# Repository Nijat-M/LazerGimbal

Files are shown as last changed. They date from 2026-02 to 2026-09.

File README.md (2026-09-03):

# 🎯 SADIR 1798-K

<div align="center">

### Autonomous Air Defense & Precision Optical Laser Tracking System
**2-Axis High-Speed Closed-Loop Gimbal with Real-Time Computer Vision, IFF Defense & STM32 Firmware**







<p align="center">
  
  
  
  
  
  
</p>

[🇬🇧 English](README.md) • [🇹🇷 Türkçe](README_TR.md)

</div>

---

<div align="center">

### 📋 TEKNOFEST 2026 Yarışma / Başvuru Bilgileri

| Başvuru Yaptığı Takım Adı | Takım ID | Başvuru ID |
| :---: | :---: | :---: |
| **Sadir Pehlivan** | **#990060** | **#5208679** |

</div>

---

## 📸 System Hardware & Field Deployment

<div align="center">
  <table>
    <tr>
      <td width="58%" align="center" valign="middle">
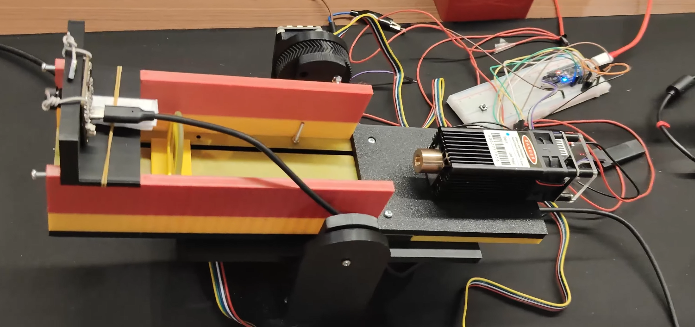
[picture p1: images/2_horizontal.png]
Laser Gimbal Hardware Rig (Close-up)
        
        <p><b>🔬 Hardware Prototype (Close-up)</b><br>
        <i>2-Axis Custom Gimbal, Optical Rail, High-Power Laser Module, Arducam Global Shutter & STM32 Controller</i></p>
      </td>
      <td width="42%" align="center" valign="middle">
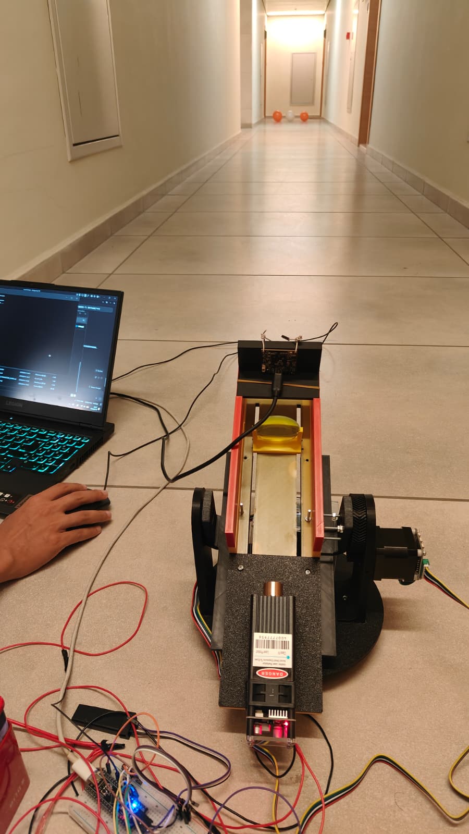
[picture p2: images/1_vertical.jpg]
15m Hallway Target Engagement Field Test
        
        <p><b>🎯 15m Long-Range Field Test</b><br>
        <i>Live Corridor Target Acquisition, Autonomous Lock-On & Real-Time PC Telemetry</i></p>
      </td>
    </tr>
  </table>
</div>

---

## 📺 Demonstration Video

<div align="center">

### 🏆 [2026 Çelikkubbe Hava Savunma Sistemleri Yarışması | Başvuru ID: 5208679](https://www.youtube.com/watch?v=ou6Uf3Ik7QI)

2026 Çelikkubbe Hava Savunma Sistemleri Yarışması | Başvuru ID: 5208679 (https://www.youtube.com/watch?v=ou6Uf3Ik7QI)

*Click the thumbnail above to watch the official competition video featuring Stage 3 autonomous engagement, live IFF friendly-protection, and precision laser tracking.*

</div>

---

## 📌 Executive Summary

**LazerGimbal SADIR 1798-K** is an industrial-grade, 2-axis closed-loop optical laser tracking and air defense gimbal platform engineered for precision target acquisition, identification, and neutralisation. Built for **TEKNOFEST 2026 Çelikkubbe Air Defense Systems Competition**, the system tightly integrates high-speed computer vision with real-time embedded hardware control.

The system is architected across three core pillars:
1. **Host AI & Vision Engine (PC / PyQt6 / Python)**: Processes live camera streams at 60 FPS (using global shutter sensors), runs multi-space IFF (Identification Friend or Foe) chromatic algorithms, and executes Ultralytics YOLO26 deep-learning target classification with zero NMS latency.
2. **Real-Time Embedded Controller (STM32F401 / C HAL)**: Executes a continuous 10kHz hardware DDA (Digital Differential Analyzer) microstep pulse engine and a 50Hz Incremental PID loop driving **Makerbase MKS SERVO42C closed-loop vector stepper motors (`CR_vFOC`)** with absolute zero step loss and high holding torque.
3. **Yetenek 6 Zero-Annotation Synthetic Pipeline**: A synthetic dataset generator that automatically renders 3MF CAD meshes into multi-angle photorealistic targets, generating labeled YOLO26 training datasets without manual bounding box annotation.

---

## 🚀 Key Innovations & Features

### 🛡️ Stage 3 Autonomous Air Defense & IFF Engine
- **Autonomous Mission Director**: A 6-state competition state machine handling target acquisition, hostile engagement, post-fire evaluation (10s), automated emergency stop (ESTOP), stabilization delay (10s), and safe shutdown.
- **Robust Multi-Space IFF (Friend or Foe)**: Combines HSV, normalized BGR differential, and CIELAB chroma spaces to reliably classify Red Hostile vs. Blue Friendly targets while eliminating ambient background false-positives (yellow walls, wood frames).
- **100% Friendly Fire Prevention**: Real-time safety interlock strictly suppresses laser firing whenever a friendly blue asset enters the reticle zone.
- **Orange Balloon Hunt Mode**: Auto-locks and engages orange balloon targets continuously until physical balloon destruction is optically verified.

### 👁️ Computer Vision & Tactical HUD (PyQt6 / Python)

<div align="center">
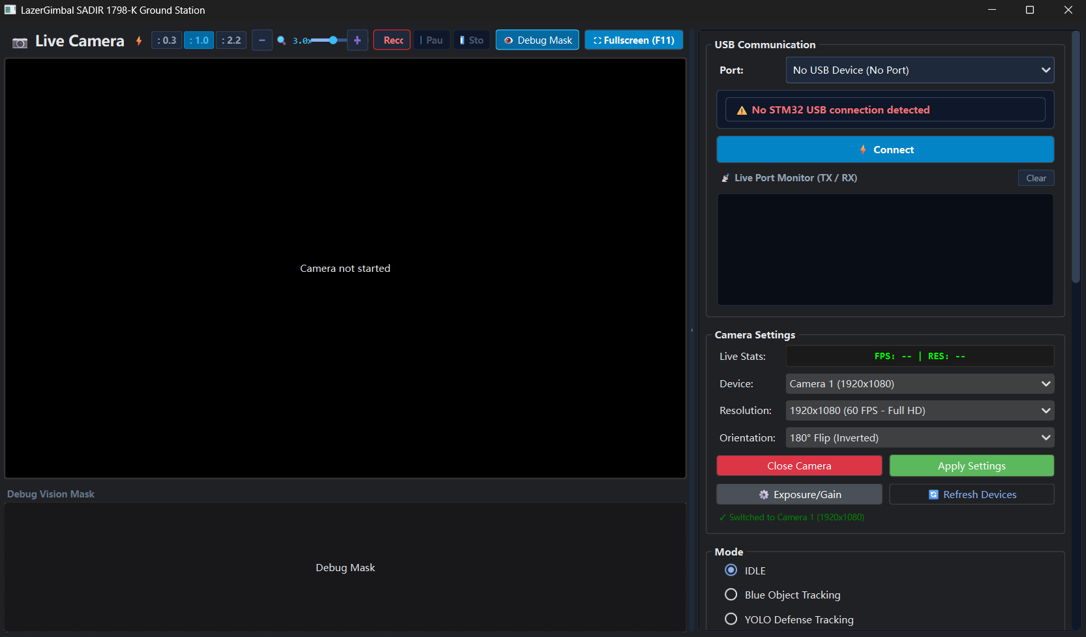
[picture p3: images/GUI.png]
Tactical GUI Dashboard
  
  <p><i>Modern Cyber-Dark PyQt6 Tactical Interface — Live Camera Feed, Dual Target Lock-On, Debug Vision Mask & Device Control</i></p>
</div>

- **Arducam AR0234 Global Shutter Camera Support**: Fully adapted for high-speed industrial global shutter sensors (1080p @ 60 FPS), eliminating rolling-shutter jello distortion under aggressive gimbal slewing.
- **Tactical PiP Zoom Reticle**: Picture-in-Picture digital magnification scope synchronized in real time with the calibrated aim crosshair.
- **Constant Frame Rate (CFR 30fps) Video Recording**: Audio-video synced `.mp4` hardware container recording with microphone ambient audio mix and full telemetry HUD OSD overlay.
- **Zero-Flicker Spatial Multi-Target Tracker**: Multi-object Euclidean association and Kalman smoothing to eliminate bounding box flickering and ID swaps.
- **Dynamic Orientation Hot-Switching**: Instant 0° / 180° inverted ceiling mount and horizontal mirror modes without software restarts.

### ⚡ Embedded Motion Control (STM32F401 / C HAL)
- **10kHz Continuous-Phase DDA Pulse Engine**: Microstep generator preserving fractional step accumulators across control cycles for ultra-smooth low-speed tracking.
- **50Hz Incremental Closed-Loop PID**: Fine-tuned closed-loop tracking with dynamic deadband compensation and friction anti-stall minimum torque feed.
- **3-Speed Motor Gearbox**: Fast toggle (Keys `1`, `2`, `3`) for Recon, Cruise, and Sprint manual motor slewing speeds.
- **5-Layer Safety Protection**:
  1. **Surge Auto-Healing Reset**: Exception handlers instantly clamp motor pins to 0V and trigger a 1ms auto-reboot (`NVIC_SystemReset()`).
  2. **Dual Watchdog Timers**: 500ms hardware telemetry timeout halts STEP pulses if communication drops; PC watchdog stops stale commands after 250ms.
  3. **Velocity & Acceleration Limiting**: Bounded motor dynamics preventing step slippage.
  4. **Coordinate Boundary Clamping**: Filters UART transmission noise.
  5. **Non-Blocking Heartbeat Indicator (`PC13`)**: Visual hardware health feedback.

### 🧠 Yetenek 6 — 3MF Synthetic Training & Classification
- **Zero-Manual-Annotation Pipeline**: Converts official competition 3MF multi-body files (`Modeller.3mf`) to STL meshes and renders realistic multi-angle targets onto real ambient backgrounds.
- **Multi-Class Air Defense Detection**: Classifies `F16` fighter jets, `HELIKOPTER` attack helicopters, `BALISTIK_FUZE` ballistic missiles, and `MINI_IHA` mini-drones across 5m, 10m, and 15m test ranges.

---

## 🛠️ Hardware Bill of Materials (BOM)

| Component | Model / Specification | Purpose |
| :--- | :--- | :--- |
| **Microcontroller** | STM32F401CCU6 (Blackpill / ARM Cortex-M4 @ 84MHz) | Real-time motion control & DDA pulse engine |
| **Motors & Drivers** | 2x NEMA 17 Stepper Motors + MKS SERVO42C Closed-Loop FOC | 2-axis Pan/Tilt drive with magnetic encoder feedback |
| **Camera Sensor** | Arducam AR0234CS Global Shutter USB Camera (1080p @ 60fps) | High-speed, distortion-free optical acquisition |
| **Laser Emitter** | 450nm High-Power Blue Laser Diode & Optics Rail | Precision target illumination & simulated engagement |
| **Power Supply** | 20V DC 2A+ Regulated Switching Power Supply | Motor power rail (`V+` / `GND`) |
| **Pan-Tilt Frame** | Custom reinforced 3D printed mechanical assembly | 2-axis rigid optical gimbal platform |

### 🔌 Hardware Pinout & Electrical Interface

| Subsystem | Signal Name | STM32F401 Pin | Connected Peripheral / Pin | Logic / Note |
| :--- | :--- | :--- | :--- | :--- |
| **Pan Axis (X)** | `X_STEP` | `PA0` (TIM2_CH1) | MKS SERVO42C `STP` Pulse | 3.3V Logic (Active High) |
| **Pan Axis (X)** | `X_DIR` | `PA4` (GPIO) | MKS SERVO42C `DIR` Direction | CW / CCW Polarity |
| **Tilt Axis (Y)** | `Y_STEP` | `PA1` (TIM2_CH2) | MKS SERVO42C `STP` Pulse | 3.3V Logic (Active High) |
| **Tilt Axis (Y)** | `Y_DIR` | `PA5` (GPIO) | MKS SERVO42C `DIR` Direction | CW / CCW Polarity |
| **Laser Emitter** | `LASER_PWM` | `PB0` (TIM3_CH3) | Laser Driver Optocoupler / TTL | 1kHz PWM Power / Gate Trigger |
| **Status Telemetry**| `HEARTBEAT` | `PC13` (GPIO) | On-board Blue LED | 500ms Non-blocking Pulse |
| **Host Link** | `USB_CDC` | `PA11` (DM) / `PA12` (DP) | PC USB 3.0 / USB-C Port | Native 12 Mbps Full-Speed CDC |
| **Motor Power** | `20V_RAIL` | External PSU | MKS Driver `V+` / `GND` | Common Ground (`COM` to STM32 GND) |

> [!NOTE]
> **Hardware Roadmap**: Breadboard wiring is utilized for rapid prototyping during preliminary trials. A custom integrated surface-mount PCB carrier board is currently in development for the final competition stage.

---

## 📂 Project Structure

```text
LazerGimbal/
├── main.py                     # Main application entry point (PyQt6 + PyTorch DLL guard)
├── run_app.bat                 # One-click Windows launch script
├── requirements.txt            # Python dependencies
├── Modeller.3mf                # Official 3MF 3D target models
├── CHANGELOG.md                # Detailed release notes & commit history
│
├── core/                       # Control & State Machine Layer
│   ├── gimbal_controller.py    # 40Hz visual tracking controller with PID & safety watchdog
│   ├── serial_thread.py        # Asynchronous high-speed serial UART communication
│   ├── stage3_mission_director.py # Stage 3 autonomous air defense state machine
│   └── control/                # Error calculation & manual mouse aim controllers
│
├── vision/                     # Computer Vision & Deep Learning Layer
│   ├── vision_worker.py        # Video capture, detection dispatcher, PiP scope & video recorder
│   ├── iff.py                  # Identification Friend or Foe (HSV + BGR + CIELAB)
│   ├── yolo_detector.py        # Ultralytics YOLO26 inference pipeline & defense model adapter
│   ├── yetenek6_detector.py    # Yetenek 6 target detection adapter
│   └── yetenek6_stabilizer.py  # Spatial-temporal anti-jitter stabilizer
│
├── gui/                        # User Interface Layer (PyQt6)
│   ├── main_window.py          # Main dashboard window & docking layout
│   └── widgets/                # Modular UI widgets (Camera, Control, Mode, IFF, Calibration, PID)
│
├── config/                     # Configuration & Calibration Storage
│   ├── vision_config.py        # Camera FOV, resolution, color profiles, aim offset
│   ├── control_config.py       # PID parameters, speed gears, motion limits
│   ├── hardware_config.py      # Serial port baud rate & step pulse definitions
│   ├── device_config.py        # Persistent hardware & camera settings
│   ├── tracking_parameters.py  # Runtime tracking & Kalman filter dynamics
│   └── yetenek6_config.py      # Yetenek 6 distance & target metrics
│
├── STM32F401/                  # Embedded MCU Firmware (C / STM32CubeIDE)
│   ├── Core/Src/main.c         # DDA pulse engine, incremental PID & safety handlers
│   └── Lazer_F401.ioc          # STM32CubeMX hardware pinout configuration
│
├── yetenek6/                   # Synthetic Dataset & YOLO26 Training Pipeline
│   ├── README_ZH.md            # Detailed pipeline guide (Chinese)
│   ├── HIZLI_BASLANGIC_TR.md   # Quick start guide (Turkish)
│   ├── models_3mf/             # Extracted STL model assets (F16, Helicopter, Missile, Drone)
│   ├── backgrounds/            # Real background environments for synthetic overlay
│   └── scripts/                # S0 Camera test -> S1 Render -> S2 Dataset -> S3 Train -> S4 Detect
├── docs/                       # Technical Research, Parameter Tuning & Roadmaps
│   ├── Phase3_Kalman_Tracking_Plan.md # Kinematic state estimation & EKF plan
│   ├── Phase4_Future_Industrial_Upgrades.md # IMU cascade, ADRC & PnP fire control plan
│   └── TRACKING_PARAMETERS_GUIDE.md # Parameter tuning baselines & physical formulas
│
└── tests/                      # Automated Unit & Integration Tests
    ├── test_stage3_balloon.py  # Stage 3 balloon defense & mission state machine test
    ├── test_balloon_hunt.py    # Orange balloon segmentation & shape validation
    ├── test_iff_color.py       # IFF chromatic discrimination test
    └── test_manual_mouse_control.py # Gimbal motion & serial command verification
```

---

## ⚡ Quick Start

### 1. Prerequisites
- **Operating System**: Windows 10 / 11 (64-bit)
- **Python**: 3.10 or higher
- **NVIDIA GPU** (Optional for CUDA-accelerated YOLO26 inference)

### 2. Installation
```bash
# Clone repository
git clone https://github.com/Nijat-M/LazerGimbal.git
cd LazerGimbal

# Create virtual environment
python -m venv .venv
.venv\Scripts\activate

# Install dependencies
pip install -r requirements.txt
```

### 3. Launch Application
```bash
python main.py
# Or run with the bundled batch file:
run_app.bat
```

---

## 📜 License & Acknowledgments

This project is licensed under the **[MIT License](LICENSE)**.

Developed for **TEKNOFEST 2026 Çelikkubbe Air Defense Systems Competition** (Takım: **Sadir Pehlivan**, Takım ID: **#990060**, Başvuru ID: **#5208679**). Special thanks to the open-source robotics and computer vision communities.

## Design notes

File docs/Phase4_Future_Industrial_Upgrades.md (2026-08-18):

# 阶段四：未来工业级控制架构升级计划 (Phase 4: Future Industrial Upgrades)

> **基准平台**：MKS SERVO42C 闭环步进系统 + STM32F401 (10kHz TIM2 DDA 步进脉冲) + 原生 USB CDC (12 Mbps) + Arducam AR0234 全局快门相机 (60 FPS) + YOLO26 目标检测  
> **目标**：对标 RoboMaster 竞赛步兵/哨兵云台及工业级光电吊舱，探索更高精度的控制算法与火控解算体系。

---

## 方案一：IMU 异构高频融合串级控制与 ADRC（自抗扰控制）

当前系统已具备下位机 10kHz DDA 步进脉冲生成与上位机 60Hz 动态超前预测。为了进一步抑制物理机械扰动（如线材拉扯阻力、减速机回差、安装基座振动），可引入多传感器融合与现代抗扰控制。

### 1. 异构双闭环串级控制 (Cascade Control)
- **核心架构**：
  - **外环（位置/角度环，60Hz）**：由上位机 60 FPS 视觉目标检测提供目标在视野中的角度偏差。
  - **内环（角速度环，1000Hz）**：在云台载荷端加装 6 轴 IMU（如 MPU6050 或工业级 ICM-42688-P），STM32 通过 I2C/SPI 以 1kHz 频率采集陀螺仪角速度 ($\omega_{\text{yaw}}, \omega_{\text{pitch}}$)。
- **技术优势**：
  - 上位机只需下发目标角速度或相对位姿，STM32 内部以 1000Hz 极高刷新率稳定角速度内环。
  - 彻底隔离外部基座晃动对视轴的干扰，实现类似微单稳定器 / 军用吊舱的独立增稳。

### 2. ADRC 自抗扰控制 (Active Disturbance Rejection Control)
- **核心思想**：利用**扩张状态观测器 (ESO)**，把系统中所有未知的外部干扰（风阻、线束弹性阻力、非线性摩擦力）以及系统内部的模型失配统一视为“总扰动”进行实时估算，并在控制输出时施加前馈反向抵消。
- **技术优势**：
  - 相比传统 PID，ADRC 无需针对不同载荷重量或摩擦力繁琐重新整定参数，自适应鲁棒性极高。

---

## 方案二：针孔相机内参标定 (Pinhole & PnP) 与火控提前量解算 (Kinematic Lead Computing)

### 1. 相机内参标定与 3D 物理射线映射
- **当前现状**：控制输入基于图像像素误差（pixel error），存在非线性光学畸变与视场角几何非线性。
- **升级目标**：
  - 使用棋盘格标定板与 OpenCV `cv2.calibrateCamera` 标定出相机的内参矩阵 $K$ 与畸变系数 $D$。
  - 将二维像素坐标 $(u, v)$ 通过逆投影矩阵还原为物理空间相机坐标系下的 3D 视线向量 $(\vec{X}, \vec{Y}, \vec{Z})$，直接解算出目标的绝对偏航角 (Yaw) 与俯仰角 (Pitch)。

### 2. 高机动目标火控提前量解算 (Ballistic Lead Computing)
- **核心逻辑**：
  - 系统从“光子撞击 CMOS 曝光” -> “USB 帧传输” -> “GPU YOLO 推理” -> “USB CDC 下发” -> “步进电机物理转动加速” 存在固定的全链路时间延迟 $t_{\text{delay}}$。
  - 测量并校准端到端延迟队列时间戳（约 $50 \sim 70\text{ms}$）。
  - 结合目标当前速度与加速度向量，求解超前预判击中点：
    $$ P_{\text{aim}} = P_{\text{current}} + \vec{V} \cdot t_{\text{delay}} + \frac{1}{2} \vec{A} \cdot t_{\text{delay}}^2 $$
  - 云台视轴直接指向目标在 $t_{\text{delay}}$ 后的预期落点，实现真正的“指哪打哪、极速封锁”。

---

## 3. 进阶路线图 (Milestones)

| 阶段 | 课题名称 | 关键技术点 | 难度 |
| :--- | :--- | :--- | :---: |
| **Phase 4.1** | 相机内参标定与角度几何解算 | `cv2.calibrateCamera`、去畸变、像素到物理弧度映射 | ★★☆☆☆ |
| **Phase 4.2** | 全链路延时测定与提前量解算 | 端到端时间戳对齐、火控预测落点计算 | ★★★☆☆ |
| **Phase 4.3** | 硬件 IMU 陀螺仪接入与 1kHz 速度内环 | STM32 SPI/I2C 驱动 ICM-42688-P，角速度反馈内环 | ★★★★☆ |
| **Phase 4.4** | 扩张状态观测器 (ESO) 与 ADRC 控制律 | 离散 ADRC 算法在 STM32 裸机上的高频部署与抗扰验证 | ★★★★★ |

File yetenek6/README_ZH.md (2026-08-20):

# Yetenek 6 — 目标探测与分类：分步实施指南

> **要求原文**：5 m、10 m、15 m 三个距离上完成不同目标类型的探测与分类，并**在用户界面上展示**能分类为 **F16 / Mini-Micro İHA / Füze / Helikopter**。
>
> **前提**：你们相机 + UI 已跑通，PC 带独显，只有 3MF 文件，目标是**先过视频这关**。
>
> **总工时**：约 17–28 小时。两人并行 1.5–2 天。

---

## 核心思路：为什么不用人工标注

你们有 3MF（三维网格文件）。用它可以**同时**做两件事：

1. **渲染出多视角贴图素材** → 合成训练图像，**边界框由程序自动算出**，人工标注量 = 0
2. **渲染出高分辨率正视图** → 送打印店做实体靶标

因为视频里的靶标是**平面打印件**，而合成数据本质上就是"把平面素材贴到背景上"——**仿真和现实高度一致**，这是这套方案精度能上来的根本原因。

**不要为了视频去 3D 打印靶标。** 一个 60 cm 的模型拆件打印要 20–40 小时，四类目标一周起步，来不及。规范能力 6 的原文分类对象就是「görseller（图像）」，打印平面靶标完全合规。

---

## 环境准备

```bash
pip install trimesh lxml networkx pillow numpy opencv-python
pip install ultralytics          # 训练与推理
pip install PyQt5                # 若 UI 用 PyQt
```

把 3MF 文件按**类别名**命名放进 `models_3mf/`：

```
models_3mf/
├── F16.3mf
├── HELIKOPTER.3mf
├── BALISTIK_FUZE.3mf
└── MINI_IHA.3mf
```

> 文件名 = 类别名，后面全流程自动沿用，UI 上会显示成 `F16 / Helikopter / Balistik Füze / Mini/Micro İHA`。

---

## 步骤 0 — 20 分钟的可行性体检（**千万别跳过**）

整个方案成败取决于一个数字：**15 m 处目标有多少像素**。先量出来。

**A. 测相机水平视场角（HFOV）**

1. 拿一个已知宽度的物体（比如 1.00 m 的纸板），放在**正好 5.00 m** 处
2. 用你们的相机拍一帧，在看图软件里量出它的**像素宽度**
3. 运行：

```bash
cd scripts
python s0_kamera.py --img_w 1920 --ref_m 1.0 --ref_d 5.0 --ref_px 640 --target_m 0.6
```

**B. 看输出的判断**

| 15 m 处像素宽 | 结论 |
|---|---|
| ≥ 80 px | 很好，直接往下走 |
| 45–80 px | 可以，训练/推理必须用 `imgsz 960` |
| 28–45 px | 临界，用 `imgsz 1280` **并且加大靶标** |
| < 28 px | **不行**，必须加大靶标或换窄视场（长焦）镜头 |

脚本最后会直接告诉你：**要在 15 m 达到 60 px，靶标需要多宽**。按这个数字去定打印尺寸。

> 规范对靶标/图像的尺寸**没有任何限制**，所以最省事的解法就是把靶标做大。60–80 cm 是个安全区间。

---

## 步骤 1 — 从 3MF 生成素材和打印图（约 30 分钟）

```bash
cd scripts
python s1_render.py --models_dir ../models_3mf --out ../out \
    --views 200 --size 512 --poster_cm 60 --poster_dpi 150
```

输出两样东西：

| 目录 | 内容 | 用途 |
|---|---|---|
| `out/sprites/<类别>/` | 每类 200 张多视角透明 PNG | 步骤 3 合成训练数据 |
| `out/posters/` | 每类 3 个颜色（红/蓝/灰）的 60 cm @150dpi 大图 | 步骤 2 送打印 |

**关键参数说明**

- `--az_range -38 38`：水平视角范围。**因为最终拍的是平面靶标，这里要收窄**（默认已收窄）。如果你们决赛要拍 3D 实体，再放宽到 `-180 180`
- `--colors kirmizi,mavi,gri`：红=敌、蓝=友、灰=中性。红蓝两色**顺便把能力 7 的素材也做出来了**，不用重复工作
- 不需要 Blender，纯 numpy + Pillow，Windows 上直接能跑

只要打印图不要训练素材时加 `--poster_only`（几秒钟出结果）。

---

## 步骤 2 — 今天就把靶标送去打印（**这是唯一的外部依赖，最容易卡住**）

拿 `out/posters/*.png` 去打印店：

- **规格**：60 cm 宽（或步骤 0 算出来的尺寸）、哑光相纸或 PP 背胶
- **裱板**：KT 板 / 泡沫板，**沿飞机轮廓裁形**（不要裁成方块——方块会让模型学到"矩形=目标"这种错误特征）
- **数量**：四类各 1 张灰色/红色版即可满足能力 6；能力 7 另需 1 红 2 蓝
- **支架**：每张背后粘一根细木条 + 简易三脚支撑，能立在地上

> 打印店当天到隔天出货。**今天下单**，别等到模型训完才想起来。成本几十里拉。

---

## 步骤 3 — 拍 30–40 张场地背景照（30 分钟，**决定精度上限**）

去你们**实际要拍视频的场地**，用**同一台相机、同样的架设高度**，拍 30–40 张空场景照片（不放靶标），涵盖：

- 不同朝向、不同时间段的光照
- 有人走动、有杂物的画面
- 阴天/晴天各来一些

放进 `backgrounds/` 目录。

> **这一步是整套方案里性价比最高的 30 分钟。** 用真实场地背景合成的数据，比用程序生成的假背景，实测精度差距非常大——因为模型不会再把背景里的杂物误判成目标。跳过这步，脚本会自动用合成背景，但误检率会明显上升。

---

## 步骤 4 — 合成训练数据集（15–25 分钟机器时间）

```bash
python s2_dataset.py --sprites ../out/sprites --bg ../backgrounds \
    --out ../dataset --n_train 5000 --n_val 500 \
    --img_w 1920 --img_h 1080 --hfov 60 --target_m 0.6
```

> `--img_w/--img_h` 填**你们相机的真实分辨率**，`--hfov` 填步骤 0 量出来的值，`--target_m` 填靶标实际宽度。

脚本干了什么：

- 目标在画面中的像素尺寸由**真实光学公式**推算：`px = img_w × 靶标宽 / (2 × 距离 × tan(HFOV/2))`
- **55% 的样本集中在 5/10/15 m 附近**（±15% 抖动），其余在 3.5–18 m 均匀分布 —— 精准对齐规范要求的三个距离
- 随距离增加模糊、亮度/对比度抖动、噪声、JPEG 压缩、旋转
- **边界框从 alpha 通道自动精确算出**，写成 YOLO 格式
- 自动生成 `data.yaml`

运行完会打印一张**像素尺寸参考表**，再确认一次 15 m 的数值合理。

---

## 步骤 5 — 训练（1–2 小时，挂机）

```bash
python s3_train.py --data ../dataset/data.yaml --model yolov8s.pt \
    --imgsz 960 --epochs 80 --batch 8 --device 0
```

**⚠️ 最容易犯的错：用默认 `imgsz 640`。**
15 m 处目标只有 40–60 px，640 输入下会被压到 15–20 px，小目标召回会断崖式下跌。**必须用 960，紧张的话用 1280。**

其他建议：

- 显存不够就调 `--batch 4`，或换 `yolov8n.pt`（更快、精度略低，对四类靶标够用）
- 训完看 `runs/detect/yetenek6/`：**mAP50 ≥ 0.85** 就可以进入下一步
- 权重在 `runs/detect/yetenek6/weights/best.pt`

---

## 步骤 6 — 真实数据微调（**强烈建议，2 小时，效果最明显**）

靶标打印回来后，在场地上按 5/10/15 m 摆好，**每类录 30 秒视频**，抽帧得到 150–300 张真实图。

- 用 [Roboflow](https://roboflow.com) 或 `labelImg` 标注 —— 只有 200 来张，**一个人 1 小时能标完**
- 混进 `dataset/images/train`，用合成模型做起点再训 20–30 epoch：

```bash
python s3_train.py --data ../dataset/data.yaml \
    --model runs/detect/yetenek6/weights/best.pt \
    --imgsz 960 --epochs 30 --name yetenek6_ft
```

这一步通常能把真实场景的 mAP 再拉高 10–20 个点，是**合成数据方案的标准收尾**。

---

## 步骤 7 — 接进你们现有的 UI（3–5 小时）

因为相机→界面链路已经通了，改动量很小：

```python
from s4_detector import HedefDedektoru

# 初始化一次
self.det = HedefDedektoru("best.pt", conf=0.35, imgsz=960,
                          hfov_deg=60, hedef_genislik_m=0.6)   # 后两个参数可选

# 原来的每帧循环里：
#   self.label.setPixmap(self.mat2pix(frame))
# 改成：
dets = self.det.tespit(frame)
self.label.setPixmap(self.mat2pix(self.det.ciz(frame, dets)))
self.tablo_guncelle(dets)      # 右侧分类列表
```

`dets` 是标准结构，方便你们接自己的逻辑：

```python
[{'sinif': 'F16', 'gorunen': 'F16', 'guven': 0.94,
  'box': (x1,y1,x2,y2), 'mesafe_m': 5.1}, ...]
```

`s5_ui_pyqt.py` 是一个可直接运行的完整 PyQt 面板（左边视频 + 右边分类表格），可以整段抄，也可以直接拿来当演示界面：

```bash
python s5_ui_pyqt.py --weights best.pt --source 0 --hfov 60 --target_m 0.6
```

**界面细节（裁判会看这些）**

- 标签用 PIL 绘制，正确显示土耳其字符 `Füze`、`İHA`（`cv2.putText` 显示不出来，这是个常见坑）
- 每类一个固定颜色，右侧表格实时列出 **HEDEF TİPİ / GÜVEN / MESAFE**
- 顶部信息条显示当前检测数量

> **距离显示是加分项，不是必需项。** 规范原文只要求「在这三个距离上完成探测和分类，并通过用户界面展示」——距离是**布置条件**，不是界面必须输出的数值。给 `hfov_deg` 和 `hedef_genislik_m` 就能顺带估出距离，不给就显示 `-`，**不要为此单独做测距模块**。

---

## 步骤 8 — 拍摄能力 6 的镜头（1 小时）

拍摄清单，逐条对照：

- [ ] 地面用**卷尺量出并贴标记** 5 m / 10 m / 15 m，让标记在画面里可见
- [ ] 每个距离**依次放上四类靶标**，镜头**同时拍到实景 + UI 屏幕**
  - 最佳做法：**屏幕录制 UI** + **手机拍现场**，后期做画中画
- [ ] UI 上必须能清楚看到**框 + 类别名 + 置信度**
- [ ] 开头打字幕卡：`Yetenek 6 — Hedef Tespit ve Sınıflandırma`
- [ ] 画面里用字幕或纸牌标出当前距离：`5 m` / `10 m` / `15 m`
- [ ] 建议 40–60 秒拍完（总时长只有 2–5 分钟，7 项能力要挤进去）

---

## 排期建议（今天 8/16 → 截止 8/20 17:00）

| 日期 | 任务 |
|---|---|
| **8/16 今天** | 步骤 0 视场角实测 → 定靶标尺寸 → **步骤 1 生成打印图 → 送打印店** → 步骤 3 拍背景照 → 步骤 4 合成数据集（跑通宵） |
| **8/17** | A：步骤 5 训练；B：步骤 7 UI 集成（**并行**） |
| **8/18** | 靶标到货 → 步骤 6 真实数据微调 → 三距离实测调参 |
| **8/19** | **拍摄全部 7 项能力 + 剪辑**（留一整天） |
| **8/20 上午** | 上传 YouTube（设「Liste dışı」）→ 描述里写时间戳 → 填 KYS 表单 → **验证链接能打开** |

> 链接打不开会**直接淘汰**，务必用无痕窗口验证一遍。

---

## 排障速查

| 现象 | 原因 / 解法 |
|---|---|
| 15 m 完全检不到 | `imgsz` 太小 → 上 1280；或靶标太小 → 重回步骤 0 重算尺寸 |
| 背景杂物被误检 | 没用真实场地背景 → 补做步骤 3，或降低 `--conf` 阈值反向验证 |
| 类别互相混淆 | 素材视角范围太宽 → 收窄 `--az_range`；或补真实数据微调（步骤 6） |
| 帧率太低卡顿 | 换 `yolov8n`；或推理降到 `imgsz 640` 但只对画面中心 ROI 裁剪后送入 |
| UI 上土耳其字符是方块 | 用 `s4_detector.ciz()`（PIL 绘制），别用 `cv2.putText` |
| 3MF 加载报错 | 用 PrusaSlicer / Bambu Studio 打开后导出 STL，把 `s1_render.py` 里的 `*.3mf` 改成 `*.stl` |
| 训练 loss 不降 | 检查 `data.yaml` 的 `names` 顺序和 `sprites/` 子目录名是否一致（脚本按字母序编号） |

---

## 文件清单

```
scripts/
├── s0_kamera.py      # 视场角测量 + 靶标尺寸规划（先跑这个）
├── s1_render.py      # 3MF → 多视角素材 + 打印海报
├── s2_dataset.py     # 素材 → YOLO 数据集（自动标注）
├── s3_train.py       # YOLOv8 训练
├── s4_detector.py    # 推理模块（接进你们 UI）
└── s5_ui_pyqt.py     # 完整 PyQt 演示面板
```

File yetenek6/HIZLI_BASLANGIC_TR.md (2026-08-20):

# Yetenek 6 — Hizli Baslangic (TR)

3MF dosyalarini `models_3mf/` icine SINIF ADIYLA koyun:
`F16.3mf`, `HELIKOPTER.3mf`, `BALISTIK_FUZE.3mf`, `MINI_IHA.3mf`

```bash
pip install -r requirements.txt
cd scripts

# 0) Kamera HFOV olcumu (1 m'lik cismi 5 m'ye koy, piksel genisligini olc)  --- ATLAMAYIN
python s0_kamera.py --img_w 1920 --ref_m 1.0 --ref_d 5.0 --ref_px 640 --target_m 0.6

# 1) 3MF -> sprite + baski posteri
python s1_render.py --models_dir ../models_3mf --out ../out --views 200 --poster_cm 60

#    -> out/posters/*.png  BUGUN matbaaya verin (KT panoya kaplatip siluet kesin)
#    -> test alaninizdan 30-40 bos fotograf cekip ../backgrounds/ icine koyun

# 2) Otomatik etiketli veri seti (elle etiketleme YOK)
python s2_dataset.py --sprites ../out/sprites --bg ../backgrounds --out ../dataset \
    --n_train 5000 --n_val 500 --img_w 1920 --img_h 1080 --hfov 60 --target_m 0.6

# 3) Egitim  (DIKKAT: imgsz 640 KULLANMAYIN, 15 m'de hedef ~45 px)
python s3_train.py --data ../dataset/data.yaml --imgsz 960 --epochs 80 --device 0

# 4) Test / arayuz
python s5_ui_pyqt.py --weights runs/detect/yetenek6/weights/best.pt \
    --source 0 --hfov 60 --target_m 0.6
```

## Mevcut arayuze entegrasyon (3 satir)

```python
from s4_detector import HedefDedektoru
self.det = HedefDedektoru("best.pt", conf=0.35, imgsz=960, hfov_deg=60, hedef_genislik_m=0.6)

dets = self.det.tespit(frame)
self.label.setPixmap(self.mat2pix(self.det.ciz(frame, dets)))
```

## Cekim kontrol listesi (Yetenek 6)
- [ ] Yerde 5 m / 10 m / 15 m serit metre ile isaretli ve kadrajda gorunuyor
- [ ] Her mesafede 4 hedef tipi sirayla
- [ ] Arayuz ekrani kayitta net gorunuyor (kutu + sinif adi + guven)
- [ ] "Yetenek 6" alt yazi karti
- [ ] 40-60 saniye

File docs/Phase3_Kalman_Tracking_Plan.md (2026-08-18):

# Phase 3: 运动学状态估计与卡尔曼高阶滤波演进方案 (Kinematic State Estimation & Kalman Roadmap)

> **适用硬件平台**：STM32F401 (10kHz TIM2 DDA 步进脉冲) + MKS SERVO42C 闭环步进电机 + Arducam AR0234 全局快门相机 (60 FPS) + 原生 USB CDC (12 Mbps) + YOLO26 目标检测  
> **状态**：阶段核心已在 [`core/control/error_processor.py`](file:///d:/LazerGimbal/core/control/error_processor.py) 与 [`TRACKING_PARAMETERS_GUIDE.md`](file:///d:/LazerGimbal/TRACKING_PARAMETERS_GUIDE.md) 中全面落地；本方案提供向高阶 2D/3D EKF 扩展的演进技术路线。

---

## 1. 现行已落地的运动学超前预测与抗抖系统

在当前项目中，为了解决视觉检测与控制链路中固有的全链路延时（约 $40 \sim 65\text{ms}$），系统已落地了一套高性能的**非对称动态超前预测与 3 区域运动学速度规划架构**：

### 1.1 动态非对称超前预测补偿 (Asymmetric Dynamic Lead Anticipation)
位于 [`ErrorProcessor.process()`](file:///d:/LazerGimbal/core/control/error_processor.py)：
- **急刹减速阶段 (fx 与 vel_x 异号)**：目标高速冲向准星中心时，系统判定为进场减速，自动施加 **$65\text{ms}$ 强效超前制动时间**，提前收油平滑制动，**彻底消除远距离大速度冲过准星与反向回摆**。
- **加速追击阶段 (fx 与 vel_x 同号)**：目标加速远离准星时，采用 **$35\text{ms}$ 敏捷超前时间**，消除视觉传输滞后，起步瞬间零延迟咬住目标。
- **零点穿越防抖**：当预测坐标跨越 0 点时强制吸附归零，避免符号翻转震荡。

### 1.2 消除果冻效应的导数噪声门限 (Anti-Jello Noise Gate)
- 当单周期像素跳变 $|\Delta y| < 1.2\text{px}$ 时，直接判定为传感器离散噪点，瞬时速度强制置 0，**彻底切断 60Hz 视觉微震源**。
- 俯仰 Y 轴结合重度低通滤波 ($\alpha = 0.35$)，彻底消除了相机滚动快门与微小机械共振引发的“果冻”扭曲。

### 1.3 3 区域运动学速度规划 (3-Zone Kinematic Servoing)
- **准星过渡区 ($< \text{SettleZone}$)**：采用渐进比例缩放 ($0.50 + 0.50 \times \frac{err}{\text{SettleZone}}$)，起步即响应，进中心柔和刹车。
- **线性追踪区 ($\text{SettleZone} \sim \text{EdgeThreshold}$)**：$1.20\times$ 敏捷线性跟踪。
- **边缘软饱和区 ($> \text{EdgeThreshold}$)**：启用亚线性幂压缩 ($100 + (err - 100)^{0.55} \times 1.2$)，限制最高速度在安全制动包线内 (~210°/s)，防止超大速度甩脱目标。

---

## 2. 高阶卡尔曼滤波 (EKF) 演进路线

为了在未来应对**复杂机动防空目标（高机动转弯、突变加速度、短暂被遮挡）**，系统可平滑升级为基于恒加速度 (CA) 模型的扩展卡尔曼滤波观测器。

### 2.1 状态向量与运动学模型 (Constant Acceleration Model)
定义目标在图像坐标系或空间物理坐标系中的 6 维状态向量：
$$ X_k = \begin{bmatrix} x & y & v_x & v_y & a_x & a_y \end{bmatrix}^T $$

状态转移矩阵 $F$（时间步长 $\Delta t = \frac{1}{60}\text{s} \approx 16.67\text{ms}$）：
$$ F = \begin{bmatrix} 
1 & 0 & \Delta t & 0 & \frac{1}{2}\Delta t^2 & 0 \\
0 & 1 & 0 & \Delta t & 0 & \frac{1}{2}\Delta t^2 \\
0 & 0 & 1 & 0 & \Delta t & 0 \\
0 & 0 & 0 & 1 & 0 & \Delta t \\
0 & 0 & 0 & 0 & 1 & 0 \\
0 & 0 & 0 & 0 & 0 & 1
\end{bmatrix} $$

### 2.2 测量更新与抗遮挡推算 (Coasting Capability)
测量向量仅包含目标检测给出的质心坐标 $Z_k = \begin{bmatrix} z_x & z_y \end{bmatrix}^T$：
$$ H = \begin{bmatrix} 
1 & 0 & 0 & 0 & 0 & 0 \\
0 & 1 & 0 & 0 & 0 & 0 
\end{bmatrix} $$

- **正常观测时**：卡尔曼增益 $K_k = P_{k|k-1} H^T (H P_{k|k-1} H^T + R)^{-1}$，融合 YOLO 视觉测量与运动惯性预测。
- **目标短暂遮挡 / 掉帧时 (Coasting 惯性航位推算)**：若 YOLO 在连续 3~10 帧未检测到目标，**不下发 STOP**，而是依靠卡尔曼先验状态矩阵 $\hat{X}_{k|k-1} = F \hat{X}_{k-1|k-1}$ 持续推算目标运动轨迹并引导云台继续追踪，当目标重新穿出遮挡物时实现无缝重捕获。

---

## 3. 分步进阶实施建议

1. **模块设计**：
   - 在 `core/control/` 目录下构建 `kalman_tracker.py`，保持与 `ErrorProcessor` 一致的接口 `process(raw_x, raw_y) -> (pred_x, pred_y)`。
2. **多假设数据关联 (Data Association)**：
   - 结合 YOLO 的国防目标类别（`BALISTIK_FUZE`, `F16`, `HELIKOPTER`, `MINI_IHA`）与马氏距离 (Mahalanobis Distance)，杜绝多目标交错时的跟丢与误跟。
3. **下位机融合**：
   - 维持下位机 10kHz DDA 闭环调速机制不变，上位机直接输出已包含卡尔曼加速度外推预测的高阶误差指令 `<err_x, err_y, fire>\n`。

---

## 4. 技术亮点与面试总结

> "针对 60 FPS 视觉制导闭环中由曝光传输与机械惯性引发的数十毫秒系统时延，我们构建了**非对称动态超前预测观测器**与 **3 区域运动学速度规划架构**；创新性地引入了方向自适应制动超前（65ms）与加速追击超前（35ms），并配合 1.2px 导数噪声门限切断果冻效应源。结合 STM32 10kHz TIM2 DDA 闭环步进驱动与双区差分阻尼控制，实现了极速响应无过冲、高精度锁定且抗遮挡的高性能光电伺服追踪。"

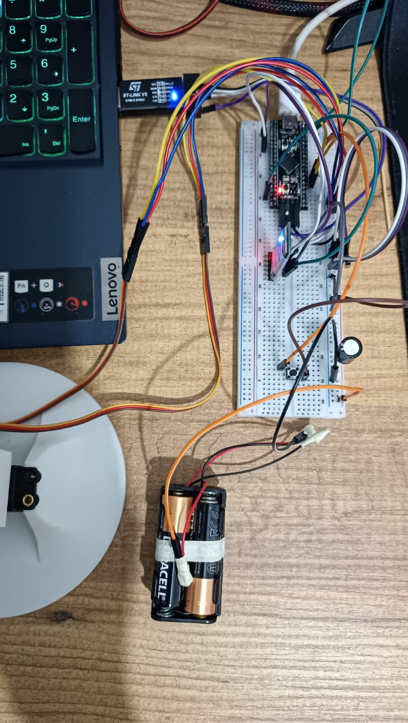
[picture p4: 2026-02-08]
images/ALL.jpeg

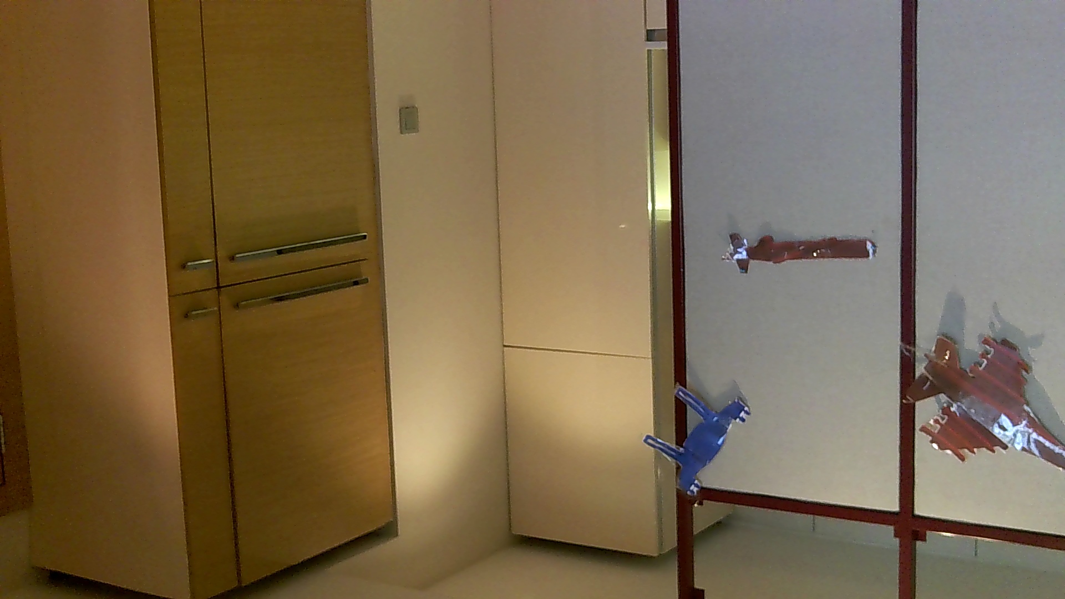
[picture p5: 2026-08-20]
yetenek6/gercek_kareler/kare_003.jpg

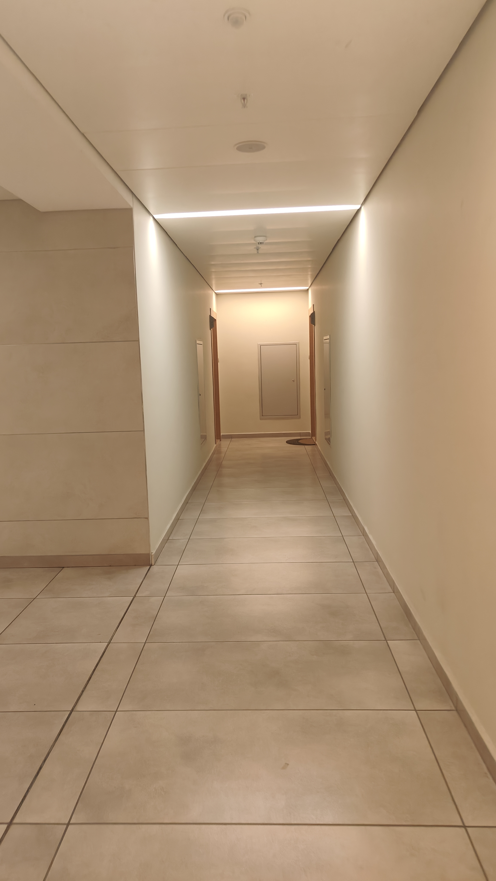
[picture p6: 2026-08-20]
yetenek6/backgrounds/IMG20260816192850.jpg.jpeg

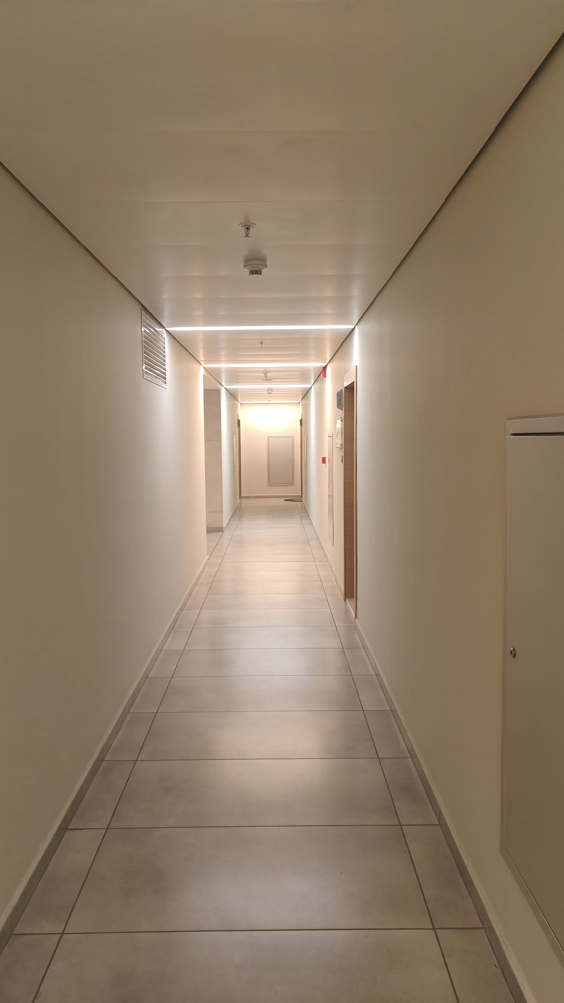
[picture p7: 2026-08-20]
yetenek6/backgrounds/IMG20260816192808.jpg.jpeg

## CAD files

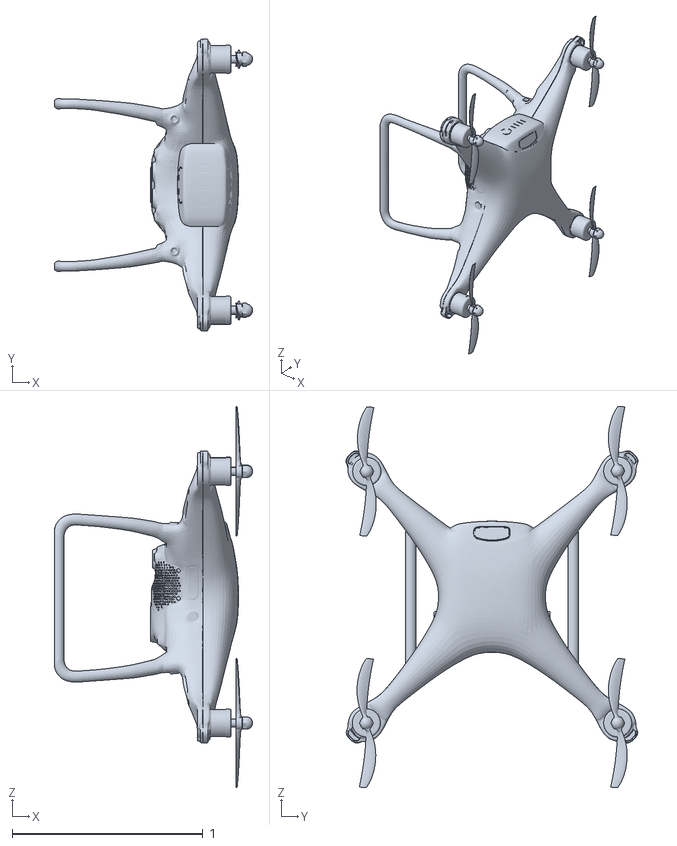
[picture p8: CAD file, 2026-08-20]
yetenek6/models_3mf/MINI_IHA.stl
1.04 x 1.53 x 2.00

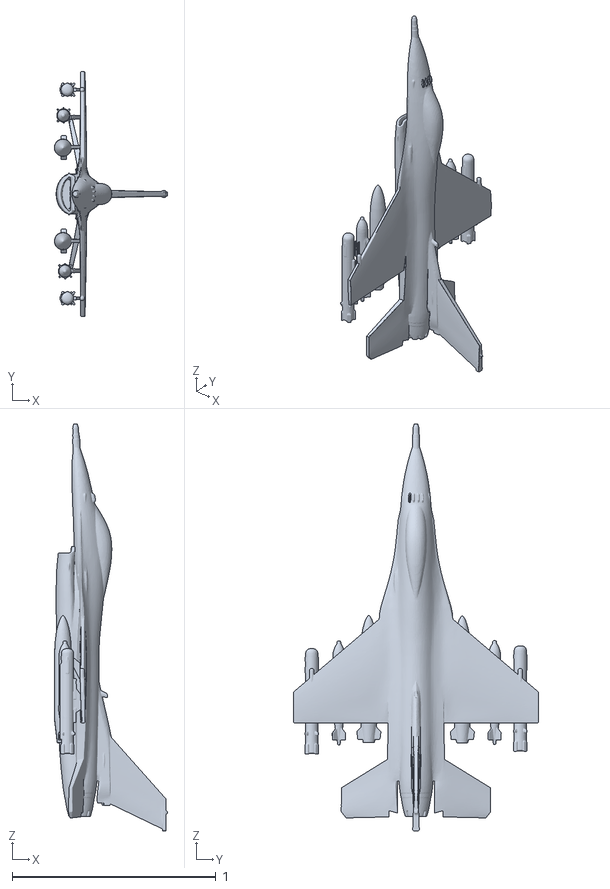
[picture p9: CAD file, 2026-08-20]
yetenek6/models_3mf/F16.stl
0.557 x 1.20 x 2.00

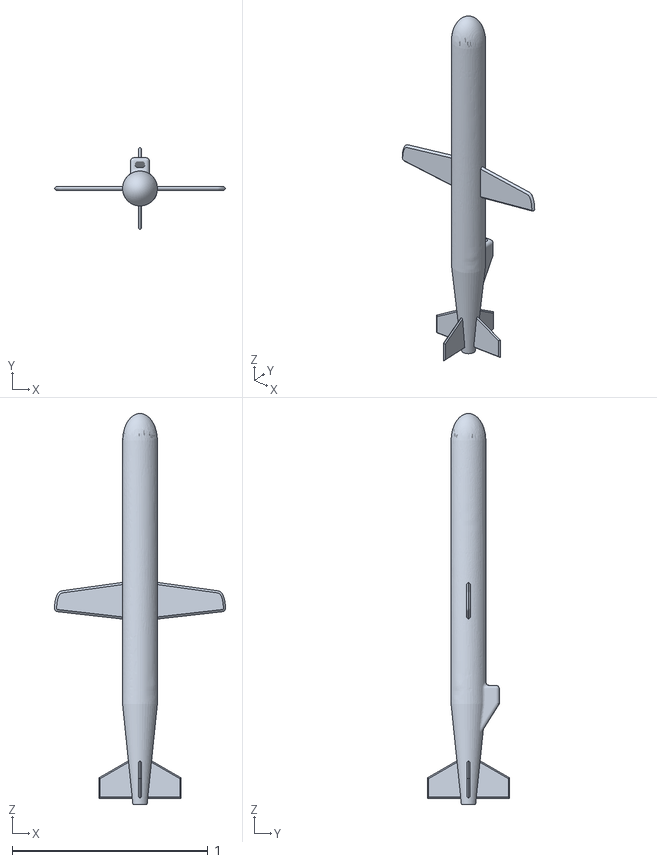
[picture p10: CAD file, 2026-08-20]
yetenek6/models_3mf/BALISTIK_FUZE.stl
0.876 x 0.421 x 2.00

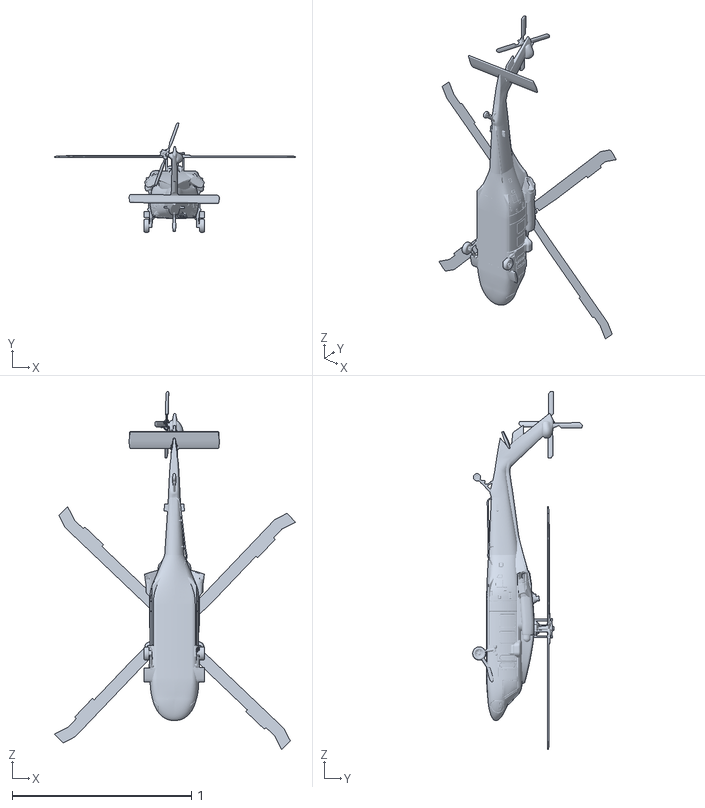
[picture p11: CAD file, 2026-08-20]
yetenek6/models_3mf/HELIKOPTER.stl
1.35 x 0.612 x 2.00

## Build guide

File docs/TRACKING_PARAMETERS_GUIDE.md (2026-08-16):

# 云台全系统追踪参数速查与调试手册 (Tracking Parameters & Tuning Guide)

> **版本**：v2.4.0 调优基线  
> **参数配置文件**：[`config/tracking_parameters.py`](file:///d:/LazerGimbal/config/tracking_parameters.py) 与 [`config/tracking_parameters.json`](file:///d:/LazerGimbal/config/tracking_parameters.json)

---

## 1. 运动学三级速度规划与防过冲参数 (3-Zone Kinematic Servoing)

| 参数名 | 推荐基线值 | 单位 | 说明与调试经验 |
| :--- | :---: | :---: | :--- |
| `CONTROL_LOOP_HZ` | `60.0` | Hz | 上位机控制循环频率，与 60 FPS 工业相机硬件曝光完全对齐。 |
| `TRACKING_SCALE_X` | `1.20` | - | X 轴（偏航轴）误差增益。调大响应更快，调过大易震颤。 |
| `TRACKING_SCALE_Y` | `0.45` | - | Y 轴（俯仰轴）误差增益。由于俯仰负载轻且易点头，取 0.40~0.50 最稳。 |
| `TRACKING_MAX_ERROR_X` | `120` | px | X 轴单周期最大输出限幅。限制最高速度在安全制动包线内 (~210°/s)，**彻底杜绝远距离大速度冲过头与回摆**。 |
| `TRACKING_MAX_ERROR_Y` | `50` | px | Y 轴单周期最大输出限幅。防止超速打到机械限位。 |
| `SETTLE_ZONE_X` | `45` | px | X 轴准星减速过渡区。进入 45px 内启动平滑刹车，使目标平稳吸附十字准心。 |
| `SETTLE_ZONE_Y` | `25` | px | Y 轴准星减速过渡区。 |
| `SETTLE_FACTOR_BASE` | `0.50` | - | 准星区起始基础增益 ($0.50 + 0.50 \times \frac{err}{SettleZone}$)，起步立刻有动力，靠近死区柔和刹车。 |
| `EDGE_COMPRESS_THRESHOLD_X` | `100` | px | X 轴屏幕边缘软饱和压缩起点。目标超出 100px 时启动亚线性幂压缩，防止边缘飞车甩脱目标。 |
| `EDGE_COMPRESS_EXPONENT` | `0.55` | - | 亚线性压缩幂指数：$err_{\text{compressed}} = 100 + (err - 100)^{0.55} \times 1.2$。 |

---

## 2. 非对称超前预测与果冻效应消除参数 (Lead Anticipation & Anti-Jello)

| 参数名 | 推荐基线值 | 单位 | 说明与调试经验 |
| :--- | :---: | :---: | :--- |
| `NOISE_GATE_THRESHOLD` | `1.2` | px | **【消除果冻效应核心】** 导数噪声死区门限。坐标变化 $<1.2\text{px}$ 直接判定为传感器噪点，瞬时速度置 0，**彻底切断 60Hz 视觉微震源**。 |
| `VELOCITY_FILTER_ALPHA_Y` | `0.35` | - | Y 轴速度估计低通滤波系数。重度滤波消除俯仰高频微抖共振。 |
| `VELOCITY_FILTER_ALPHA_X` | `0.55` | - | X 轴速度估计低通滤波系数。 |
| `LEAD_TIME_BRAKE_X` | `0.065` | s (65ms) | **【远距离防过冲核心】** 高速向中心逼近时的超前刹车时间。根据进场速度提前 65ms 平滑收油，**杜绝冲过中心反向回摆**。 |
| `LEAD_TIME_ACCEL_X` | `0.035` | s (35ms) | 目标加速远离准星时的超前追击时间。消除 35ms 视觉滞后，起步瞬间咬住目标。 |
| `LEAD_TIME_BRAKE_Y` | `0.055` | s (55ms) | Y 轴急刹阶段超前时间。 |
| `LEAD_TIME_ACCEL_Y` | `0.025` | s (25ms) | Y 轴追击阶段超前时间。 |
| `MAX_PIXEL_JUMP_X` | `350` | px/frame | 单帧允许的最大跳变步长，防止跳变框导致云台瞬间抽搐。 |

---

## 3. 下位机闭环 PID 与死区控制 (Closed-Loop PID)

| 参数名 | 推荐基线值 | 单位 | 说明与调试经验 |
| :--- | :---: | :---: | :--- |
| `KP` | `0.60` | - | 比例系数。敏捷跟手，平稳无超调。 |
| `KI` | `0.16` | - | 积分系数。消除稳态静差。 |
| `KD` | `0.50` | - | 微分系数。高速阻尼，抑制中高频振荡。 |
| `DEADZONE` | `5` | px | 准星中心死区。误差在 $\pm 5\text{px}$ 内强制锁定为 0，防止电机频繁微动发热。 |
| `VISION_WATCHDOG_TIMEOUT` | `0.25` | s | 视觉看门狗。250ms 未收到新坐标自动平滑急停。 |

---

## 4. 深度学习 YOLO 识别与防误判参数 (YOLO Tracking)

| 参数名 | 推荐基线值 | 说明与调试经验 |
| :--- | :---: | :--- |
| `DEFAULT_YOLO_MODEL` | `savunma_yolo26.pt` | 国防防空模型（4类目标：BALISTIK_FUZE, F16, HELIKOPTER, MINI_IHA）。 |
| `YOLO_CONF_THRESHOLD` | `0.50` | 默认置信度。0.50 能有效阻隔室内杂乱背景与低置信度虚警。 |
| `YOLO_DEFENSE_IMGSZ` | `960` | 防空模型原生训练尺寸。在 GPU (CUDA) 下以 960 推理，小目标识别特征大幅增强。 |
| `YOLO_MIN_BOX_SIZE` | `16` px | 最小目标边长。过滤小于 16 像素的杂散噪点框。 |
| `YOLO_LOCK_DISTANCE_THRESHOLD` | `180` px | 连续追踪目标最大跳变锁定阈值，结合同类别优先逻辑防止脱锁乱跳。 |

---

## 5. 颜色 / 蓝色物体追踪参数 (Color Tracking)

| 参数名 | 推荐基线值 | 说明与调试经验 |
| :--- | :---: | :--- |
| `HSV_BLUE_LOWER` | `[100, 120, 50]` | 蓝色 HSV 识别下限。 |
| `HSV_BLUE_UPPER` | `[135, 255, 255]` | 蓝色 HSV 识别上限。 |
| `MIN_CONTOUR_AREA` | `300.0` px | 最小有效蓝色目标轮廓面积。 |
| `PYRAMID_DOWNSCALE_WIDTH` | `640` px | 金字塔下采样基准宽度。将 1080p 图像耗时由 18ms 压缩至 1.5ms，释放 60~120 FPS 高帧率潜能。 |

---

## 6. 下位机 STM32 固件对应参数 (STM32 Firmware Reference)

| 固件宏定义 | 推荐值 | 说明 |
| :--- | :---: | :--- |
| `STEP_TIMER_HZ` | `10000.0` Hz | TIM2 步进脉冲调度时基 (10kHz DDA)。 |
| `PID_CONTROL_HZ` | `50.0` Hz | 固件 PID 解算频率。 |
| `MAX_STEP_ACCEL` | `10000.0` steps/s² | 步进电机最大加速度（实现毫秒级起步与强力制动）。 |
| `FRICTION_BREAKAWAY_RATE_X` | `120.0` steps/s | X 轴克服静摩擦起步前馈，在准星中心 15px 内平滑衰减至 0。 |
| `d_gain_x (近距离 / 远距离)` | `160.0` / `25.0` | 近距离强效定点急刹，远距离快速跟手。 |

---

## 7. 如何在代码中加载或备份参数？

```python
from config.tracking_parameters import TrackingParameters

# 1. 导出当前参数为 JSON 备份
TrackingParameters.save_to_json("config/my_tuning_backup.json")

# 2. 从 JSON 恢复参数
TrackingParameters.load_from_json("config/my_tuning_backup.json")

# 3. 实时读取参数
max_err = TrackingParameters.TRACKING_MAX_ERROR_X
print(f"当前 X 轴最大误差限幅: {max_err}")
```

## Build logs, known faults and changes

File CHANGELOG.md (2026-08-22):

# Changelog

<div align="right">
  🇬🇧 <a href="CHANGELOG.md">English</a> | 🇹🇷 <a href="CHANGELOG_TR.md">Türkçe</a>
</div>

### [v0.5.0] - 2026-08-20
- **Yetenek 6 Zero-Manual-Annotation 3MF Synthetic AI Dataset & Training Pipeline**:
  - Engineered an automated synthetic pipeline generating labeled datasets directly from official competition 3MF models (`Modeller.3mf`), eliminating manual bounding box labeling.
  - Implemented automated multi-angle target rendering with lighting variation and realistic hallway/room background compositing (`yetenek6/scripts/s0` ~ `s6`).
  - Added native multi-class air defense model training and inference support for 4 critical aerial targets: `F16` (Fighter Jet), `HELIKOPTER` (Attack Helicopter), `BALISTIK_FUZE` (Ballistic Missile), and `MINI_IHA` (Mini/Micro UAV) across 5m, 10m, and 15m competition ranges.
  - Deployed `yetenek6_best.pt` air-defense deep learning model with strict confidence threshold filtering and dynamic class discovery.
  - Built spatial-temporal target stabilizer (`yetenek6_stabilizer.py`) and anti-jitter filtering for thin missile and aircraft geometries.
- **Stage 3 Autonomous Air Defense Mission & IFF Separation (Çelikkubbe Competition)**:
  - Designed and deployed `Stage3MissionDirector` autonomous 6-state competition sequence: 1. Hostile Target Acquisition & Lock -> 2. Continuous Tracking & Laser Engagement -> 3. Post-Engagement Wait (10s) -> 4. Automated Emergency Stop (ESTOP) Trigger -> 5. Post-ESTOP Stabilization Delay (10s) -> 6. Safe System Shutdown.
  - Upgraded IFF (Identification Friend or Foe) chromatic engine (`vision/iff.py`) combining HSV, normalized BGR differential, and CIELAB chroma spaces, reliably distinguishing Red Hostile vs. Blue Friendly targets under yellow lighting and ambient reflections.
  - Implemented 100% Friendly Fire Interlock to strictly suppress laser firing whenever friendly blue targets enter the reticle zone.
  - Added Orange Balloon Hunt Mode (`BALLOON_HUNT`) with persistent lock-on and optical destruction verification.
- **Tactical HUD, PiP Reticle Scope & High-Fidelity Video Recording**:
  - Implemented synchronized Picture-in-Picture (PiP) tactical magnification scope with live crosshair alignment and real-time zoom controls (`[` / `]`).
  - Added Constant Frame Rate (CFR 30fps) `.mp4` video recording with wall-clock frame pacing, microphone ambient audio capture, and automated AAC audio-video muxing.
  - Introduced 3-speed motor gear selector (Keys `1`, `2`, `3` for Recon, Cruise, and Fast Slewing speeds).
  - Added dedicated manual D-Pad jog controls and live STM32 serial monitor logging.

### [v0.4.5] - 2026-08-16
- **Savunma YOLO26 Air-Defense Neural Model Adaptation & Tactical Defense HUD**:
  - Integrated `savunma_yolo26.pt` air-defense model with automatic model discovery and native **960×960 GPU inference** resolution.
  - Added target class filtering for 4 defense target classes (`BALISTIK_FUZE`, `F16`, `HELIKOPTER`, `MINI_IHA`) with dynamic class-consistent tracking.
  - Implemented tactical defense HUD overlays with threat-level color coding, crosshair lock-on percentage, and offset vectors.
  - Built Model Selection, Class Selection, and Confidence threshold tuning controls in `ModePanel`.
- **Zero-Lag Dynamic Lead Anticipation & Phase Compensator**:
  - Replaced legacy sluggish coordinate low-pass filters with a **Dynamic Phase-Lead Compensator** ($\tau_{\text{lead}} = 35\text{ms} \sim 65\text{ms}$), eliminating closed-loop phase lag and hunting oscillations.
  - Added predictive braking anticipation: automatically anticipates arrival when approaching the crosshair at high speed, achieving overshoot-free lock-on.
- **Y-Axis Rolling-Shutter Jello Effect Elimination**:
  - Introduced derivative noise-gating deadband (`|\Delta y| < 1.2\text{px} \implies \text{Vel} = 0`) to cut off 60Hz discrete sensor pixel noise from driving high-frequency pitch micro-vibrations.
  - Implemented heavy velocity low-pass smoothing on the pitch axis (`\alpha = 0.35`), completely eliminating CMOS rolling shutter jello distortion.
- **3-Zone Kinematic Servoing & Far-Distance Overshoot Elimination**:
  - Re-engineered full-field 3-zone motion profile: Settle Zone progressive deceleration ($0.50 \sim 1.00$), Linear Tracking Zone ($1.20\times$), and Edge Soft-Saturation Compression ($e_{\text{compressed}} = 100 + (e - 100)^{0.55} \times 1.2$).
  - Bounded maximum tracking output (`TRACKING_MAX_ERROR_X = 120`) within the safe braking envelope (~210°/s), eliminating extreme-distance runaway and reverse back-swinging.
- **Standalone Parameter Archive & Tuning Guide**:
  - Created centralized [`config/tracking_parameters.py`](file:///d:/LazerGimbal/config/tracking_parameters.py) and [`config/tracking_parameters.json`](file:///d:/LazerGimbal/config/tracking_parameters.json).
  - Authored comprehensive tuning guide [`TRACKING_PARAMETERS_GUIDE.md`](file:///d:/LazerGimbal/TRACKING_PARAMETERS_GUIDE.md) with parameter baseline references and physical formulas.

### [v0.4.4] - 2026-08-16

- **Industrial Visual Servo Closed-Loop Architecture & Adaptive Differential Braking**:
  - Re-engineered STM32 firmware motion control from legacy incremental PID to a high-speed **Position-to-Velocity Visual Servo** control law with active differential braking.
  - Implemented **Adaptive Dual-Zone Differential Damping**: applies low damping ($D=25.0f$) during high-speed chasing for zero-drag acceleration, and automatically engages heavy damping ($D=160.0f$) within the central 25px zone for instant, overshoot-free crosshair lock-on.
- **Dry Friction Breakaway Feedforward for Unbearinged Chassis**:
  - Added dynamic stiction compensation (`FRICTION_BREAKAWAY_RATE_X = 120.0f`) with linear center attenuation (<15px), eliminating start-up deadband sluggishness on pan axes without bearings while preventing slow-speed hunting/oscillation.
- **Hardware Performance Unleashed (9000 steps/s & 10000 steps/s²)**:
  - Boosted firmware speed limits to `MAX_STEP_RATE = 9000.0f` (~1000°/s) and `MAX_STEP_ACCEL = 10000.0f`, delivering ultra-responsive high-speed target tracking.
- **60 FPS Real-Time Control Pipeline Synchronization**:
  - Synchronized Python host control loop to **60.0 Hz** (`CONTROL_LOOP_HZ = 60.0`) matching the 60 FPS camera capture frequency.
  - Decoupled X/Y tracking scales and added Y-axis center damping and soft travel limits.

### [v0.4.2] - 2026-08-16
- **Complete Native USB CDC (12 Mbps) Migration & Bluetooth Deprecation**:
  - Successfully migrated STM32F401 hardware firmware from legacy Bluetooth UART (115.2 kbps) to **STM32 Native USB CDC Virtual COM Port (12 Mbps Full-Speed)**.
  - Re-engineered STM32 clock tree for exact **48.0 MHz USB clock** via 25MHz HSE ($PLLM=25, PLLN=336, PLLP=4, PLLQ=7$).
  - Integrated official ST USB Device Core & CDC class middlewares, implementing bidirectional microsecond-latency control streaming.
  - Thoroughly purged all legacy Bluetooth / USART1 firmware code (`usart.c`, `usart.h`, `HAL_UART` driver modules, and ISR handlers), completely freeing `PA9` and `PA10` pins on STM32 for future industrial expansion.
- **Intelligent GUI Hardware Recognition & Responsive Layout**:
  - Re-designed `SerialPanel` with card layout and automatic word-wrapping, eliminating text clipping across varying display scaling factors.
  - Added smart USB device identification matching STMicroelectronics USB CDC (VID: `0x0483`, PID: `0x5740`) with automatic port pre-selection and real-time connection state indicators.

### [v0.4.1] - 2026-08-16
- **Ultralytics YOLO26 NMS-Free Engine & CUDA 12.6 Hardware Acceleration**:
  - Fully integrated the latest **Ultralytics YOLO26** (`yolo26n.pt`) native end-to-end framework, completely eliminating NMS (Non-Maximum Suppression) post-processing overhead and target bounding jitter.
  - Activated NVIDIA CUDA 12.6 hardware acceleration with FP16 tensor core execution on RTX 3060, dropping inference latency down to ~30ms.
  - Thoroughly purged legacy YOLOv8 model remnants, unneeded checkpoints, and legacy code bloat.
- **Asynchronous Decoupled Visual Pipeline (`AsyncYOLODetector`)**:
  - Built an asynchronous double-buffered worker that decouples the main 60 FPS camera capture & UI rendering stream from background GPU neural inference.
  - Completely neutralized micro-stuttering and uneven frame-pacing across 1080p/720p/480p, delivering a perfectly smooth 60.0 FPS live feed while sustaining high-frequency target coordinate updates.
- **Arducam AR0234 Global Shutter Industrial Camera Adaptation**:
  - Fully integrated and optimized for Arducam AR0234 Global Shutter (Onsemi AR0234CS) high-speed cameras, eliminating motion blur and rolling-shutter jello distortion during rapid gimbal panning.
  - Enforced prioritized `CAP_PROP_FOURCC = 'MJPG'` DirectShow hardware compression negotiation to eliminate USB bandwidth bottlenecks.
  - Added dedicated DirectShow hardware settings trigger (`CAP_PROP_SETTINGS`), allowing microsecond-level manual Exposure Time, Gain, and White Balance tuning directly from the UI.
- **Pyramid Multi-Scale Detection Acceleration & Single-Pass Pipeline**:
  - Implemented real-time pyramid subsampling in `TargetDetector`: 1080p frames are downscaled on-the-fly for color segmentation and morphological filtering, reducing CPU latency from 18ms down to **~3.2ms (5.5x speedup)**.
  - Restored rock-solid **60.0 FPS** in active tracking modes (`BLUE_TRACKING` / `TRACKING`) with zero frame drops.
  - Preserved sub-pixel precision with automatic coordinate and bounding radius upscale mapping.
- **Instant Frame Orientation & Inverted-Mount Hot-Switching**:
  - Added zero-latency frame flipping (`Normal`, `180° Inverted (Upside-Down Mount)`, `Vertical Flip`, `Horizontal Mirror`) applied at the capture ingress before detection, keeping PID coordinate polarity 100% unified.
- **GUI Camera Panel Streamlining & Bug Fixes**:
  - Reorganized camera panel with clean dual-column button groupings (`Open/Close` & `Apply`, `Exposure/Gain Settings` & `Refresh Devices`).
  - Standardized resolution presets focused on the golden **60 FPS** gimbal tracking frequency (`640x480`, `1280x720`, `1920x1080`).
  - Fixed `AttributeError: 'ModePanel' object has no attribute 'get_current_mode'` on start control toggle.

### [v0.4.0] - 2026-08-16
- **MKS SERVO42C Closed-Loop Stepper Motor Upgrade**: Replaced legacy MG996R RC servos with high-precision NEMA 17 stepper motors and Makerbase MKS SERVO42C closed-loop vector FOC (`CR_vFOC`) drivers powered by 20V DC for ultra-high holding torque, anti-stall protection, and zero lost steps.
- **10kHz Hardware DDA Microstep Pulse Generator**: Rewrote STM32F401 firmware around a native 10kHz hardware timer interrupt (`TIM2`) with Bresenham / DDA real-time pulse interpolation, delivering whisper-quiet, ultra-smooth microstepping at 50Hz Incremental PID velocity loops.
- **5-Layer Industrial Safety & Fault Protection**:
  - Auto-healing exception handler (`HardFault_Handler` / `Error_Handler`) instantly clamps motor pins to 0V and self-resets (`NVIC_SystemReset()`) in 1ms against back-EMF / power surges.
  - 2.0-second hardware visual watchdog automatically engages braking and holding torque on telemetry disconnect.
  - Slew rate velocity limiter (`MAX_STEPS_PER_CYCLE = 80`) and physical UART coordinate clamping ($\pm 400\text{px}$) to prevent motor runaway.
  - 500ms non-blocking heartbeat LED (`PC13`) for visual proof of hardware health.
- **Enhanced Manual & Keyboard Control**:
  - Dual-mode manual control: Tap/short-press for crisp single-step jog, press-and-hold for smooth 40Hz continuous rotation with instant release braking.
  - Selectable Keyboard Control Mode with dedicated toggle switch for `WASD` / Arrow keys (`↑ / ↓ / ← / →`) with OS auto-repeat filtering.
  - Differentiated axis inertia compensation (X-axis base inertia boost vs Y-axis pitch precision).
- **Smart Tracking Control Linkage**: One-click "Start Control" button with automatic serial/camera readiness validation and seamless tracking mode engagement.

### [v0.3.7] - 2026-08-09

- **GUI & Control Refactor**: Updated PyQt6 interface components (Camera view, Camera panel, Serial panel) with improved stats display and control signals.
- **Gimbal Controller Stability**: Enhanced thread loop performance, refined watchdog mechanisms, and optimized telemetry handling.
- **Vision Model & Logging**: Integrated default YOLOv8 model weights (`yolov8n.pt`) alongside YOLO26 support, and standardized logging across vision worker threads.
- **Automated Launcher**: Added `run_app.bat` script for automated environment setup and dependency initialization.

### [v0.3.6] - 2026-03-19
- **YOLO26 Tracking Engine**: Upgraded computer vision architecture from YOLOv8 to the cutting-edge NMS-Free YOLO26 `yolo26n.pt` model, substantially reducing bounding-box jitter and latency.
- **Center-Distance Data Association**: Implemented Euclidean distance-based target locking (`150px` threshold) instead of naive highest-confidence selection, securing persistent lock-on across frames.
- **Zero-Latency Error Processor**: Stripped out legacy `deque` moving average software filters in favor of raw 0-delay error passthrough with a structural `.max_pixel_jump` safety clamp.
- **Multithreaded PID Concurrency**: Decoupled the `GimbalController` from the PyQt `QTimer` event loop into an independent async Thread running at a rigid 40Hz (`time.perf_counter()`), neutralizing UI freeze impact on PID derivates.
- **Serial Comm Unblocking**: Rewrote `serial_thread.py` to prevent `readline()` deadlocks, securing microsecond-level telemetry transmission without queue blockage.
- **STM32 Edge-Case Mitigations**: 
  - Deployed `new_data_flag` logic to prevent "Blind Integral Windup" on asynchronous telemetry loss.
  - Rectified "Derivative Kick" spikes by ensuring continuous error-state flow when exiting deadzones.
  - Integrated Slew Rate Limiters (`MAX_SERVO_DELTA`) to protect physical servos from gear-stripping snapbacks.

### [v0.3.5] - 2026-03-19
- **STM32 Incremental PID**: Reverted the mathematically explosive positional PID algorithm on the STM32 to a true Incremental PID system, ensuring stable and reliable motor velocity output.
- **UI Deadzone Tuning**: Added a dedicated Deadzone control slider to the PID tuning panel. This allows structural "hunting" oscillation across stationary targets (caused by low camera framerate/delays) to be software filtered out.
- **Architectural Cleanup**: Removed hardcoded scaling tables and obsolete logic (`CONTROL_DEADZONE_LEVELS`, `ERROR_SCALING`) from `error_processor` enabling pure linear tracking control.
- **Industrial Tracking Roadmaps**: Documented future upgrade pathways (Kalman Filter, ADRC, Kinematic Lead Calculation) towards a professional-grade continuous tracking structure.

### [v0.3.0] - 2026-03-13
- **YOLOv8 Object Tracking**: Added Deep Learning capability with Ultralytics YOLOv8. 
- **Multi-Target Detection**: System can now scan and highlight multiple objects in the frame simultaneously (Yellow boxes) while selecting and tracking the most confident target (Red Box with `[LOCKED]` label).
- **Dynamic Object Switching**: YOLO mode is configured to track any COCO dataset object dynamically, easily adaptable for specialized datasets (e.g., Drone tracking, Face tracking) by swapping the `.pt` models.
- **Dependency Loading Fix**: Resolved `WinError 1114` PyTorch CUDA runtime and PyQt6 DLL overlap issues ensuring smooth loading on Windows environments.

### [v0.2.0] - 2026-03-12
- **Power System Upgrade**: Integrated a 12V DC Adapter with an XL4016 Buck Converter to provide a dedicated, stable 6V power supply for the gimbal servos.
- **Framework Refactor & Bug Fixes**: Comprehensive codebase restructuring and resolution of several critical issues, including:
    - Fixed instability in serial communication for more reliable hardware commands.
    - Improved consistency of visual tracking for better target lock.
    - Stabilized PID control logic for significantly smoother movements.
    - Overhauled Graphical User Interface (GUI) for a more modern and intuitive aesthetic.
    - Enhanced step size and deadzone algorithms to increase tracking speed and responsiveness.

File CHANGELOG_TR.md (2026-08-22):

# Değişiklik Günlüğü (Changelog)

<div align="right">
  🇬🇧 <a href="CHANGELOG.md">English</a> | 🇹🇷 <a href="CHANGELOG_TR.md">Türkçe</a>
</div>

### [v0.5.0] - 2026-08-20
- **Yetenek 6 Sıfır Manuel Etiketlemeli 3MF Sentetik Veri Seti ve YOLO Eğitim Hattı**:
  - Yarışma resmi 3MF modellerinden (`Modeller.3mf`) doğrudan etiketli eğitim verisi üreten tam otomatik sentetik veri hattı geliştirildi; el ile etiketleme ihtiyacı tamamen ortadan kaldırıldı.
  - Çok açılı hedef renderlama, ışık varyasyonları ve gerçek koridor/iç mekan arka planlarına otomatik bindirme algoritmaları entegre edildi (`yetenek6/scripts/s0` ~ `s6`).
  - 5m, 10m ve 15m yarışma mesafelerinde 4 kritik hava savunma hedefi için çok sınıflı model desteği: `F16` (Savaş Uçağı), `HELIKOPTER` (Taarruz Helikopteri), `BALISTIK_FUZE` (Balistik Füze) ve `MINI_IHA` (Mini/Mikro İHA).
  - `yetenek6_best.pt` hava savunma derin öğrenme modeli entegre edildi; dinamik model tarama ve sıkı güven eşiği (confidence) filtrelemesi eklendi.
  - İnce füze gövdeleri ve hava hedefleri için uzamsal-zamansal hedef stabilizatörü (`yetenek6_stabilizer.py`) ve titreme önleyici filtreler geliştirildi.
- **Aşama 3 (Stage 3) Otonom Hava Savunma Görevi ve IFF Ayrıştırması (Çelikkubbe Yarışması)**:
  - `Stage3MissionDirector` 6 aşamalı otonom yarışma durum makinesi geliştirildi: 1. Düşman Hedef Tespiti ve Kilitlenme -> 2. Kesintisiz Takip ve Lazer Angajmanı -> 3. Atış Sonrası Bekleme (10s) -> 4. Acil Durdurma (ESTOP) Tetikleme -> 5. ESTOP Sonrası Dengeleme Beklemesi (10s) -> 6. Güvenli Sistem Kapanışı.
  - Çok uzaylı (HSV + normalize BGR farkı + CIELAB) IFF (Dost/Düşman Tanıma) motoru (`vision/iff.py`) ile sarı ortam ışığı ve yansımalarda dahi kırmızı düşman ve mavi dost hedefler hatasız ayrıştırıldı.
  - Nişangaha mavi dost unsur girdiğinde lazer ateşlemesini anında bloke eden %100 Dost Unsur Koruma Kilidi eklendi.
  - Turuncu Balon Avı Modu (`BALLOON_HUNT`) ile sürekli kilitlenme ve görsel imha doğrulaması sağlandı.
- **Taktik HUD, PiP Büyüteç Dürbünü ve Yüksek Doğruluklu Video Kaydı**:
  - Nişangahla senkronize çalışan Taktik PiP (Picture-in-Picture) dijital yakınlaştırma dürbünü ve gerçek zamanlı büyütme kontrolleri (`[` / `]`) eklendi.
  - Duvar saati zaman damgalı Sabit Kare Hızlı (CFR 30fps) `.mp4` video kaydı, mikrofon ortam sesi kaydı ve otomatik AAC ses-video birleştirme özelliği eklendi.
  - 3 kademeli motor vites sistemi (`1`, `2`, `3` kısayolları ile Keşif, Seyir ve Hızlı İntikal) eklendi.
  - Arayüze özel manuel D-Pad motor jog kontrol paneli ve canlı STM32 seri port izleme monitörü entegre edildi.

### [v0.4.5] - 2026-08-16
- **Savunma YOLO26 Hava Savunma Modeli Uyarlaması ve Taktik Savunma HUD**:
  - `savunma_yolo26.pt` hava savunma modeli otomatik model algılama ve GPU üzerinde yerel **960×960 çözünürlük** ile entegre edildi.
  - 4 hedef sınıfı (`BALISTIK_FUZE`, `F16`, `HELIKOPTER`, `MINI_IHA`) için hedef filtreleme ve sınıfsal kararlı takip eklendi.
  - Tehdit seviyesi renk kodlaması, kilitlenme yüzdesi ve ofset vektörlü taktik HUD arayüzü entegre edildi.
  - `ModePanel` arayüzüne Model Seçimi, Sınıf Seçimi ve Güven Eşiği (Confidence) ayar kontrolleri eklendi.
- **Sıfır Gecikmeli Dinamik Faz İleri Beslemesi (Phase-Lead Anticipation)**:
  - Eski düşük geçiren filtrelerin neden olduğu gecikme kaldırıldı ve **Dinamik Faz İleri Dengeleyicisi** ($\tau_{\text{lead}} = 35\text{ms} \sim 65\text{ms}$) eklendi; hedef etrafında sallanma (hunting oscillation) tamamen yok edildi.
  - Hedefe yüksek hızla yaklaşırken otomatik erken frenleme tahmini ile aşım olmadan tam merkezde durma sağlandı.
- **Y Ekseni Jöle Efektinin (Rolling-Shutter Jello) Tamamen Giderilmesi**:
  - Türev gürültü kesme eşiği (`|\Delta y| < 1.2\text{px} \implies \text{Hız} = 0`) ile kamera piksel gürültüsünden kaynaklanan 60Hz yüksek frekanslı mikro titreşimler kesildi.
  - Y ekseni hız kestirimine derin alçak geçiren filtre (`\alpha = 0.35`) uygulanarak CMOS rolling shutter jöle dalgalanması tamamen yok edildi.
- **3 Bölgeli Kinematik Hız Planlaması ve Uzak Mesafe Aşım Önleme**:
  - 3 bölgeli hareket eğrisi geliştirildi: Merkez Frenleme Bölgesi ($0.50 \sim 1.00$), Lineer Takip Bölgesi ($1.20\times$) ve Kenar Yumuşak Doyum Sıkıştırması ($e_{\text{compressed}} = 100 + (e - 100)^{0.55} \times 1.2$).
  - Maksimum takip çıkışı (`TRACKING_MAX_ERROR_X = 120`) güvenli frenleme sınırları içinde sınırlandırılarak uzak mesafeden ani dönüşlerdeki savrulma ve geri salınım engellendi.
- **Bağımsız Parametre Arşivi ve Ayar Kılavuzu**:
  - Bağımsız [`config/tracking_parameters.py`](file:///d:/LazerGimbal/config/tracking_parameters.py) ve [`config/tracking_parameters.json`](file:///d:/LazerGimbal/config/tracking_parameters.json) oluşturuldu.
  - Parametre taban değerleri ve formülleri içeren kapsamlı [`TRACKING_PARAMETERS_GUIDE.md`](file:///d:/LazerGimbal/TRACKING_PARAMETERS_GUIDE.md) kılavuzu yayınlandı.

### [v0.4.4] - 2026-08-16

- **Endüstriyel Görsel Servo Kapalı Çevrim Mimarisi ve Uyarlanabilir Diferansiyel Frenleme**:
  - STM32 bellenim hareket kontrolü eski artımsal PID yapısından yüksek hızlı **Konumdan Hıza Görsel Servo (Position-to-Velocity Visual Servo)** ve aktif diferansiyel frenleme modeline dönüştürüldü.
  - **Uyarlanabilir Çift Bölgeli Diferansiyel Sönümleme**: Yüksek hızlı takip sırasında düşük sönümleme ($D=25.0f$) uygulayarak sürtünmesiz ivmelenme sağlarken, merkezdeki 25px hedefe girildiğinde otomatik olarak ağır sönümleme ($D=160.0f$) devreye sokularak aşım (overshoot) olmadan anında hedefe kilitlenme sağlandı.
- **Rulmansız Tabanlar İçin Kuru Sürtünme Ayrılma İleri Beslemesi (Stiction Compensation)**:
  - Rulmansız X ekseni tabanındaki kuru sürtünmeyi aşmak için dinamik ileri besleme (`FRICTION_BREAKAWAY_RATE_X = 120.0f`) ve merkezde lineer sönümleme (<15px) eklendi; kalkış gecikmesi giderilirken düşük hızdaki salınımlar tamamen yok edildi.
- **Donanım Performansının Zirvesi (9000 steps/s ve 10000 steps/s²)**:
  - Bellenim hız sınırları `MAX_STEP_RATE = 9000.0f` (~1000°/s) ve `MAX_STEP_ACCEL = 10000.0f` seviyesine çıkarılarak ultra tepkisel ve yüksek hızlı hedef takibi sağlandı.
- **60 FPS Gerçek Zamanlı Kontrol Senkronizasyonu**:
  - Python kontrol döngüsü 60 FPS kamera frekansıyla 1:1 uyumlu olacak şekilde **60.0 Hz** (`CONTROL_LOOP_HZ = 60.0`) olarak güncellendi; X/Y ölçekleri ayrıştırıldı ve Y ekseni mekanik koruma sönümlemesi eklendi.

### [v0.4.2] - 2026-08-16
- **Tam Yerel USB CDC (12 Mbps) Geçişi ve Bluetooth Kodlarının Tamamen Temizlenmesi**:
  - STM32F401 donanım bellenimi eski Bluetooth UART (115.2 kbps) yapısından **STM32 Yerel USB CDC Sanal COM Port (12 Mbps Full-Speed)** mimarisine başarıyla taşındı.
  - STM32 saat ağacı (Clock Tree) 25MHz HSE üzerinden tam **48.0 MHz USB saati** sağlayacak şekilde yeniden yapılandırıldı ($PLLM=25, PLLN=336, PLLP=4, PLLQ=7$).
  - Resmi ST USB Device Core & CDC sınıfı ara yazılımları entegre edilerek mikrosaniye gecikmeli çift yönlü veri akışı sağlandı.
  - Eski Bluetooth / USART1 bellenim kodları (`usart.c`, `usart.h`, `HAL_UART` sürücü modülleri ve kesme işleyicileri) tamamen kaldırılarak STM32 üzerindeki `PA9` ve `PA10` pinleri gelecekteki endüstriyel genişletmeler için tamamen serbest bırakıldı.
- **Akıllı Donanım Tanıma ve Duyarlı GUI Arayüzü**:
  - `SerialPanel` kart düzeni ve otomatik metin sarma ile yeniden tasarlandı; farklı DPI ve ekran ölçeklerinde metin kırpılması tamamen engellendi.
  - STMicroelectronics USB CDC (VID: `0x0483`, PID: `0x5740`) akıllı USB donanım eşleme ve otomatik port seçimi eklendi.

### [v0.4.1] - 2026-08-16
- **Ultralytics YOLO26 NMS-Free Motoru ve CUDA 12.6 Donanım Hızlandırması**:
  - En güncel **Ultralytics YOLO26** (`yolo26n.pt`) yerel uçtan uca mimarisi entegre edildi; NMS (Non-Maximum Suppression) işlem yükü ve hedef kutularındaki titremeler tamamen ortadan kaldırıldı.
  - RTX 3060 üzerinde FP16 Tensör Çekirdekleri ile çalışan NVIDIA CUDA 12.6 GPU hızlandırması devreye alınarak çıkarım süresi 30ms altına indirildi.
  - Eski YOLOv8 model kalıntıları ve gereksiz ağırlık dosyaları temizlendi.
- **Asenkron Ayrıştırılmış Görsel İşlem Hattı (`AsyncYOLODetector`)**:
  - 60 FPS kamera yakalama/arayüz çizim akışı ile arka plan GPU derin öğrenme çıkarımını tamamen birbirinden ayıran çift tamponlu asenkron mimari kuruldu.
  - 1080p, 720p ve 480p çözünürlüklerdeki mikro-takılmalar (micro-stuttering) ve düzensiz kare aralıkları giderilerek 60.0 FPS pürüzsüz canlı izleme ve kesintisiz hedef takibi sağlandı.
- **Arducam AR0234 Global Shutter Endüstriyel Kamera Uyarlaması**:
  - Arducam AR0234 Global Shutter (Onsemi AR0234CS) yüksek hızlı endüstriyel kamera entegrasyonu; hızlı gimbal dönüşlerinde oluşan hareket bulanıklığı (motion blur) ve jello/rolling-shutter bozulması tamamen ortadan kaldırıldı.
  - DirectShow üzerinde öncelikli `CAP_PROP_FOURCC = 'MJPG'` donanımsal sıkıştırma anlaşması ile USB bant genişliği darboğazları çözüldü.
  - Arayüze eklenen `CAP_PROP_SETTINGS` donanım paneli butonu ile mikrosaniye düzeyinde manuel Pozlama Süresi (Exposure), Kazanç (Gain) ve Beyaz Dengesi ayarı sağlandı.
- **Piramit Çok Ölçekli Algılama Hızlandırması ve Tek Geçişli HSV İşleme**:
  - `TargetDetector` modülünde piramit alt örnekleme (pyramid subsampling) mimarisi uygulandı: 1080p kareler renk ayrımı ve morfolojik filtreleme için çalışma anında optimize edilerek CPU işlem gecikmesi 18ms'den **~3.2ms'ye düşürüldü (5.5 kat hızlanma)**.
  - Aktif takip modlarında (`BLUE_TRACKING` / `TRACKING`) kare düşmesi engellenerek stabil **60.0 FPS** tam kare hızı güvenceye alındı.
  - Hedef koordinatları ve yarıçapları orijinal 1080p tam çözünürlüğe alt piksel hassasiyetiyle otomatik geri eşlendi.
- **Anlık Görüntü Yönü ve Ters Montaj (Upside-Down) Sıcak Değişimi**:
  - Algılama öncesinde doğrudan yakalama akışına uygulanan sıfır gecikmeli görüntü çevirme (`Normal`, `180° Ters Montaj Çevirme`, `Dikey Çevirme`, `Yatay Ayna`) eklendi; PID koordinat polaritesi kusursuz korundu.
- **GUI Kamera Paneli Düzenlemesi ve Hata Düzeltmeleri**:
  - Kamera kontrol paneli çift sütunlu ergonomik buton gruplarıyla (`Aç/Kapat` & `Uygula`, `⚙️ Pozlama/Kazanç Ayarı` & `🔄 Cihazları Yenile`) modernize edildi.
  - Çözünürlük seçenekleri gimbal takip için ideal altın oran olan **60 FPS** standartlarına uyarlandı (`640x480`, `1280x720`, `1920x1080`).
  - Kontrolü Başlat butonuna tıklandığında oluşan `AttributeError: 'ModePanel' object has no attribute 'get_current_mode'` hatası giderildi.

### [v0.4.0] - 2026-08-16
- **MKS SERVO42C Kapalı Çevrim Step Motor Yükseltmesi**: Eski MG996R RC servolar, 20V DC endüstriyel güç beslemeli, yüksek torklu NEMA 17 step motorlar ve Makerbase MKS SERVO42C vektör FOC (`CR_vFOC`) kapalı çevrim sürücülerle değiştirildi. Adım kaybı (lost steps) tamamen ortadan kaldırıldı.
- **10kHz Donanımsal DDA Mikro-Adım Darbe Üreticisi**: STM32F401 ürün yazılımı, 10kHz donanımsal zamanlayıcı kesmesi (`TIM2`) ve Bresenham / DDA gerçek zamanlı darbe enterpolasyonuyla yeniden yazıldı. 50Hz Artımlı PID döngüsü ile titreşimsiz ve ultra akıcı hareket sağlandı.
- **5 Katmanlı Endüstriyel Güvenlik ve Hata Koruma Mimarisi**:
  - Güç dalgalanmalarına ve ani akım şoklarına karşı motor pinlerini anında 0V'a çeken ve 1 milisaniyede kendini yeniden başlatan (`NVIC_SystemReset()`) otomatik iyileşen `HardFault_Handler` entegrasyonu.
  - 2.0 saniye kesintisiz görsel güvenlik bekçisi (Watchdog) ile bağlantı koptuğunda otomatik frenleme ve şaft kitleme.
  - Darbe hızı sınırlayıcı (`MAX_STEPS_PER_CYCLE = 80`) ve seri port koordinat kısıtlaması ($\pm 400\text{px}$) ile motor kontrol dışı dönmelerine karşı koruma.
  - 500ms bloklanmayan durum bildirim LED'i (`PC13`) ile donanım çalışma göstergesi.
- **Gelişmiş Manuel ve Klavye Kontrolü**:
  - Çift modlu kontrol: Kısa tıklama ile tek adımlık hassas mikro-adım, basılı tutma ile 40Hz pürüzsüz sürekli dönüş ve bırakıldığında anında frenleme.
  - Ayrı bir anahtarla etkinleştirilen `WASD` / Yön tuşları (`↑ / ↓ / ← / →`) klavye kontrol modu ve otomatik tekrarlama filtresi.
  - Eksen atalet dengelemesi (X ekseni gövde ağırlığı kompanzasyonu ve Y ekseni hassasiyet kalibrasyonu).
- **Akıllı Takip Kontrol Bağlantısı**: Seri port ve kamera durumunu otomatik doğrulayan ve tek tıklamayla görsel takip algoritmasını başlatan akıllı "Kontrolü Başlat" butonu.

### [v0.3.7] - 2026-08-09

- **Arayüz ve Kontrol Yenilemesi (GUI & Control Refactor)**: PyQt6 arayüz bileşenleri (Kamera görünümü, Kamera paneli, Seri panel) geliştirilmiş durum göstergeleri ve sinyal yapılarıyla güncellendi.
- **Gimbal Kontrolcüsü Stabilitesi**: İş parçacığı (thread) döngüsü performansı artırıldı, güvenlik (watchdog) mekanizmaları ve telemetri işleme optimize edildi.
- **Yapay Zeka Modeli ve Günlükleme**: YOLO26 desteğinin yanında varsayılan YOLOv8 model ağırlıkları (`yolov8n.pt`) entegre edildi, iş parçacıkları genelinde standart günlükleme (logging) sağlandı.
- **Otomatik Başlatıcı**: Otomatik ortam kurulumu ve bağımlılık başlatması için `run_app.bat` betiği eklendi.

### [v0.3.6] - 2026-03-19
- **YOLO26 Takip Motoru (Tracking Engine)**: Bilgisayarlı görü mimarisi YOLOv8'den son teknoloji NMS-Free (Non-Maximum Suppression içermeyen) YOLO26 `yolo26n.pt` modeline yükseltildi. Sınırlayıcı kutu (bounding-box) titremeleri ve algılama gecikmeleri önemli ölçüde azaltıldı.
- **Merkez-Mesafe Odaklı Veri İlişkilendirme**: Saf yüksek güven (confidence) seçimi yerine, Öklid mesafesine dayalı hedef kilitleme algoritması (`150px` eşik değeri) uygulandı. Bu sayede kareler arasında kalıcı ve kararlı bir hedef kilidi (lock-on) sağlandı.
- **Sıfır Gecikmeli Hata İşlemcisi**: Yazılımsal `.max_pixel_jump` güvenlik kısıtlayıcısı kullanılarak, eski `deque` hareketli ortalama (moving average) yazılım filtreleri kaldırıldı. Yerini "Sıfır Gecikmeli (0-delay)", ham ve doğrudan hata iletimi aldı.
- **Çok İş Parçacıklı PID Eşzamanlılığı**: `GimbalController`, PyQt `QTimer` ana olay döngüsünden (event loop) ayrıştırılarak, doğrudan `40Hz` (`time.perf_counter()`) frekansta çalışan bağımsız bir asenkron iş parçacığına (Thread) dönüştürüldü. Arayüzde (UI) yaşanabilecek saniyelik donmaların PID türev (derivative) hesaplamalarını bozmasının önüne geçildi.
- **Bloklanmayan Seri Haberleşme**: `serial_thread.py` modülü `readline()` tıkanmalarını (deadlock) tamamen önleyecek şekilde yeniden yazıldı. Telemetri aktarımlarında kuyruk bloklanmaları önlenerek mikrosaniye düzeyinde iletişim güvence altına alındı.
- **STM32 Uç Durum (Edge-Case) Korumaları**: 
  - Asenkron telemetri kaybı yaşandığında "Kör İntegral Birikmesini (Blind Integral Windup)" önlemek için `new_data_flag` mantığı devreye alındı.
  - Ölü bölgeden (deadzone) çıkarken oluşan hedef sapmalarını önlemek adına, hata akışı durum sürekliliği güvence altına alınarak "Türev Sıçraması (Derivative Kick)" düzeltildi.
  - Motor dişlilerinin kırılmasını ve yüksek akım şoklarını önlemek amacıyla mekanik fiziksel servolara Dönüş Hızı Limitörleri/Kısıtlayıcıları (`MAX_SERVO_DELTA`) entegre edildi.

### [v0.3.5] - 2026-03-19
- **STM32 Artımlı (Incremental) PID**: STM32 mikrodenetleyicisi üzerindeki matematiksel olarak patlamaya müsait Konumsal PID algoritması, kararlı ve güvenilir motor hız çıkışı sağlayan sistemler için kalibre edilmiş gerçek bir "Artımlı (Incremental) PID" sistemine çevrildi.
- **Arayüz Üzerinden (UI) Ölü Bölge (Deadzone) Ayarı**: PID ayar paneline özel bir 'Ölü Bölge' kontrol kaydırıcısı eklendi. Sabit hedeflerdeki zayıf kamera fps hızlarının/gecikmelerin veya piksel gürültülerinin yol açtığı yapısal motor avlanma (hunting/osilasyon) durumu yazılımsal olarak filtrelenebildi.
- **Mimari Temizlik**: Doğrudan saf doğrusal (linear) sistem takibi sağlamak üzere, eski koddaki katı oranlama tabloları ve kullanılmayan yapılar (`CONTROL_DEADZONE_LEVELS`, `ERROR_SCALING`) `error_processor` dosyasından kaldırıldı.
- **Endüstriyel Takip Yol Haritası**: Geleceğe dönük profesyonel sürekli takip yapısı (Kalman Filtresi, ADRC, Kinematik Öncü Hesaplaması) yolları formüle edilerek belgelendirildi.

### [v0.3.0] - 2026-03-13
- **YOLOv8 Nesne Takibi (Object Tracking)**: Ultralytics YOLOv8 kullanılarak Derin Öğrenme (Deep Learning) özellikleri eklendi. 
- **Çoklu Hedef (Multi-Target) Algılama**: Sistem artık çerçeve (frame) içerisindeki birden fazla nesneyi aynı anda tarayıp vurgulayabiliyor (Sarı kutular), tüm bunların içinden de sisteme gelen güven skoru en yüksek olan asıl hedefi seçip kilitleyebiliyor (Kırmızı kutu ile `[LOCKED]` yazısı).
- **Dinamik Nesne (Object) Geçişi**: YOLO modu COCO veri kümesi nesnelerini esnekçe takip edecek biçimde ayarlandı. Özel `.pt` modelleri ile Drone, İnsan Yüzü ve Araç takibine de uygun yapısı sayesinde dış eğitim verisi setleriyle (dataset) kolay adaptasyon sağlandı.
- **Bağımlılık (Dependency) Yükleme Yaması**: Windows sistemleri için sorunsuz yüklenmeyi temin etmek adına `WinError 1114` PyTorch CUDA çalışma zamanı kütüphanesi hataları ve PyQt6 DLL modül çakışmaları düzeltildi.

### [v0.2.0] - 2026-03-12
- **Güç (Power) Altyapısı Yükseltmesi**: Gimbal servo hareketlerini sabit 6V'ta izole sunabilmek için, XL4016 modülü donatılmış 12V DC güç adaptörü kullanılarak bütünleşik enerji sistemi güçlendirildi.
- **Çatı ve Kritik Hata Düzenlemeleri (Refactor & Bug Fixes)**: Yazılım iskeletini güçlendirme kapsamında detaylı hata çözümleri yapıldı:
    - Daha güvenilir donanım komutu iletimleri için seri haberleşme tutarsızlıkları giderildi.
    - Hedef üzerine görsel kilitlenmenin (target lock) kalitesi perçinlendi.
    - Daha yumuşak gimbal dönüşleri için PID kontrolcüsü stabilize edildi.
    - Genel hisiyat ve kullanıcı kolaylığı standartlarını modernize etmek üzere Grafiksel Kullanıcı Arayüzü (GUI) elden geçirildi.
    - Hedef tepki hızlarını güçlendirmek için adım atış değerleri ve ölü bölge limit parametreleri yeniden ele alındı.

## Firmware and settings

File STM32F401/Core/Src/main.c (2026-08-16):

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
/* Includes ------------------------------------------------------------------*/
#include "main.h"
#include "tim.h"
#include "gpio.h"
#include "usb_device.h"
#include "usbd_cdc_if.h"

/* USER CODE BEGIN Includes */
#include <stdlib.h> // abs, atoi, atof
#include <string.h>
#include <stdio.h>
#include <math.h>   // fabsf
/* USER CODE END Includes */

/* USER CODE BEGIN PTD */
typedef enum {
    STATE_IDLE,
    STATE_RECEIVING_POS,
    STATE_RECEIVING_TUNING,
    STATE_RECEIVING_COMMAND
} RxState;
/* USER CODE END PTD */

/* USER CODE BEGIN PD */
#define RX_BUFFER_SIZE 64
#define STEP_TIMER_HZ 10000.0f            // TIM2 STEP 脉冲调度频率
#define PID_CONTROL_HZ 50.0f              // 保留现有 50Hz PID 解算频率
#define PID_SUBTICKS_PER_CYCLE 200U       // 10kHz / 200 = 50Hz
#define MAX_STEP_RATE 9000.0f             // 最大 9000 steps/s (高达 ~1000°/s 极速追击)
#define MAX_STEP_ACCEL 10000.0f           // 最大加速度 10000 steps/s^2 (毫秒级起步与强力制动)
#define FRICTION_BREAKAWAY_RATE_X 120.0f  // X 轴克服静摩擦起步前馈 (中心区平滑线性衰减)
#define MAX_RATE_CHANGE_PER_CYCLE (MAX_STEP_ACCEL / PID_CONTROL_HZ)
#define TRACKING_SLOW_ZONE_PIXELS 20.0f   // 准星中心 20px 核心区
#define VISION_TIMEOUT_CYCLES 24U         // 含最多20ms对齐延迟，总超时不超过500ms
#define DEADZONE_PIXELS 5                 // 与上位机默认死区一致
/* USER CODE END PD */


/* USER CODE BEGIN PV */

// PID 参数 (与上位机 GUI 实时同步)
volatile float Kp = 0.60f, Ki = 0.16f, Kd = 0.50f;

// USB 发布完整待处理包，TIM2 通过递增序号原子消费。
volatile int16_t pending_error_x = 0;
volatile int16_t pending_error_y = 0;
volatile uint8_t pending_fire = 0;
volatile uint32_t rx_packet_sequence = 0;
uint32_t consumed_packet_sequence = 0;

// 仅由 TIM2 修改的当前视觉误差与 PID 历史
int16_t current_error_x = 0;
int16_t current_error_y = 0;
int16_t prev_error_x = 0;
int16_t prev_error_y = 0;
int16_t prev_prev_error_x = 0;
int16_t prev_prev_error_y = 0;

// 电机速度规划与 10kHz 连续相位 DDA 状态
volatile uint16_t pid_subtick_counter = 0;
volatile float target_step_rate_x = 0.0f;
volatile float target_step_rate_y = 0.0f;
volatile float current_step_rate_x = 0.0f;
volatile float current_step_rate_y = 0.0f;
volatile float step_phase_x = 0.0f;
volatile float step_phase_y = 0.0f;
volatile uint8_t pulse_active_x = 0;
volatile uint8_t pulse_active_y = 0;

// 运行控制与安全标志
uint8_t current_fire = 0;
volatile uint8_t laser_power = 100;    // 激光功率百分比 (0-100%)
volatile uint8_t laser_enabled = 0;   // 激光主使能状态 (PA7 + PB0)
uint16_t vision_timeout_counter = 0;
uint8_t stop_holdoff_cycles = 0;
volatile uint8_t stop_requested = 0;  // 仅由 TIM2 消费并执行的急停请求

// 通讯接收状态机变量 (USB CDC 高速通道)
volatile RxState rx_state = STATE_IDLE;
char rx_buffer[RX_BUFFER_SIZE];
volatile uint8_t rx_index = 0;

/* USER CODE END PV */

void SystemClock_Config(void);
/* USER CODE BEGIN PFP */
void Laser_Init(void);
void Laser_SetPower(uint8_t power_percent);
void Laser_SetState(uint8_t enable);
static float LimitTrackingRate(float pid_step_delta, int16_t error);
static float RampMotorRate(float current_rate, float target_rate);
static void RequestStop(void);
static void ApplyStopMotion(void);
static void ResetPosition(void);
void Process_Protocol_Byte(uint8_t byte);
/* USER CODE END PFP */

/* USER CODE BEGIN 0 */

/**
 * @brief 初始化激光硬件外设 (默认处于绝对安全断电状态)
 */
void Laser_Init(void)
{
    // PA7 硬件使能先拉低
    HAL_GPIO_WritePin(LASER_EN_GPIO_Port, LASER_EN_Pin, GPIO_PIN_RESET);
    // PB0 TIM3_CH3 PWM 占空比初始化为 0
    __HAL_TIM_SET_COMPARE(&htim3, TIM_CHANNEL_3, 0);
    HAL_TIM_PWM_Start(&htim3, TIM_CHANNEL_3);
    laser_enabled = 0;
}

/**
 * @brief 设置激光输出功率百分比
 * @param power_percent 0 ~ 100
 */
void Laser_SetPower(uint8_t power_percent)
{
    if (power_percent > 100) power_percent = 100;
    laser_power = power_percent;
    // 如果当前激光处于使能开启状态，实时更新 PWM 占空比
    if (laser_enabled) {
        __HAL_TIM_SET_COMPARE(&htim3, TIM_CHANNEL_3, (uint32_t)laser_power);
    }
}

/**
 * @brief 设置激光开启/关闭使能状态 (双重安全联动)
 * @param enable 1: 开启, 0: 关闭
 */
void Laser_SetState(uint8_t enable)
{
    laser_enabled = enable ? 1 : 0;
    if (laser_enabled) {
        // 先打开硬件使能开关 PA7，再输出 PWM 功率 PB0
        HAL_GPIO_WritePin(LASER_EN_GPIO_Port, LASER_EN_Pin, GPIO_PIN_SET);
        __HAL_TIM_SET_COMPARE(&htim3, TIM_CHANNEL_3, (uint32_t)laser_power);
    } else {
        // 先清零 PWM 占空比 PB0，再强制拉低 PA7 硬件使能
        __HAL_TIM_SET_COMPARE(&htim3, TIM_CHANNEL_3, 0);
        HAL_GPIO_WritePin(LASER_EN_GPIO_Port, LASER_EN_Pin, GPIO_PIN_RESET);
    }
}

static float LimitTrackingRate(float target_rate, int16_t error)
{
    if (!isfinite(target_rate)) {
        return 0.0f;
    }

    float abs_error = fabsf((float)error);
    if (abs_error < (float)DEADZONE_PIXELS) {
        return 0.0f;
    }

    float rate_limit = MAX_STEP_RATE;
    if (abs_error < TRACKING_SLOW_ZONE_PIXELS) {
        rate_limit *= abs_error / TRACKING_SLOW_ZONE_PIXELS;
    }

    if (target_rate > rate_limit) target_rate = rate_limit;
    if (target_rate < -rate_limit) target_rate = -rate_limit;
    return target_rate;
}

static float RampMotorRate(float current_rate, float target_rate)
{
    if (!isfinite(current_rate) || !isfinite(target_rate)) {
        return 0.0f;
    }
    if (target_rate > MAX_STEP_RATE) target_rate = MAX_STEP_RATE;
    if (target_rate < -MAX_STEP_RATE) target_rate = -MAX_STEP_RATE;

    // 换向时必须先减速到零，禁止 STEP/DIR 瞬间反转。
    if ((current_rate > 0.0f && target_rate < 0.0f) ||
        (current_rate < 0.0f && target_rate > 0.0f)) {
        target_rate = 0.0f;
    }

    float difference = target_rate - current_rate;
    float next_rate = target_rate;
    if (fabsf(difference) > MAX_RATE_CHANGE_PER_CYCLE) {
        next_rate = current_rate + ((difference > 0.0f) ?
                                    MAX_RATE_CHANGE_PER_CYCLE :
                                    -MAX_RATE_CHANGE_PER_CYCLE);
    }

    if (next_rate > MAX_STEP_RATE) next_rate = MAX_STEP_RATE;
    if (next_rate < -MAX_STEP_RATE) next_rate = -MAX_STEP_RATE;
    return next_rate;
}

static void RequestStop(void)
{
    stop_requested = 1;
}

static volatile uint8_t manual_laser_state = 0;

static void ApplyStopMotion(void)
{
    current_error_x = 0;
    current_error_y = 0;
    prev_error_x = 0;
    prev_error_y = 0;
    prev_prev_error_x = 0;
    prev_prev_error_y = 0;
    consumed_packet_sequence = rx_packet_sequence;
    target_step_rate_x = 0.0f;
    target_step_rate_y = 0.0f;
    current_step_rate_x = 0.0f;
    current_step_rate_y = 0.0f;
    step_phase_x = 0.0f;
    step_phase_y = 0.0f;
    
    // 强制拉低脉冲引脚
    if (pulse_active_x) {
        HAL_GPIO_WritePin(GPIOA, X_STP_Pin, GPIO_PIN_RESET);
        pulse_active_x = 0;
    }
    if (pulse_active_y) {
        HAL_GPIO_WritePin(GPIOA, Y_STP_Pin, GPIO_PIN_RESET);
        pulse_active_y = 0;
    }
    
    // 强制立即断电并关闭激光
    manual_laser_state = 0;
    current_fire = 0;
    Laser_SetState(0);
    vision_timeout_counter = 0;
    stop_holdoff_cycles = 3; // 丢弃 STOP 后约 60ms 内可能仍在传输的旧运动包
    stop_requested = 0;
}

static void ResetPosition(void)
{
    // 当前硬件没有原点开关；该命令只停止并重置控制状态。
    // 禁止在 USB 接收中断中调用 HAL_Delay，否则会阻塞 SysTick。
    RequestStop();
    HAL_GPIO_TogglePin(LED_GPIO_Port, LED_Pin);
}

/**
 * @brief 统一协议解析器 (全双工支持 USB CDC 与 USART)
 * @param byte 接收到的单字节
 */
void Process_Protocol_Byte(uint8_t byte)
{
    // STOP 抢占指令
    if (byte == '!') {
        rx_state = STATE_RECEIVING_COMMAND;
        rx_index = 0;
    }
    else if (rx_state == STATE_IDLE)
    {
        if (byte == '<') {
            rx_state = STATE_RECEIVING_POS;
            rx_index = 0;
        } else if (byte == '{') {
            rx_state = STATE_RECEIVING_TUNING;
            rx_index = 0;
        }
    }
    else if (rx_state == STATE_RECEIVING_POS)
    {
        if (byte == '>') {
            rx_buffer[rx_index] = '\0';
            
            // 解析 <Error_X,Error_Y,Fire>
            char *token1 = strtok((char*)rx_buffer, ",");
            char *token2 = strtok(NULL, ",");
            char *token3 = strtok(NULL, ",");
            
            if (token1 && token2 && token3) {
                int parsed_x = atoi(token1);
                int parsed_y = atoi(token2);
                
                // 工业级物理输入限幅：防止乱码或意外超大误差导致电机失控
                if (parsed_x > 400) parsed_x = 400;
                if (parsed_x < -400) parsed_x = -400;
                if (parsed_y > 400) parsed_y = 400;
                if (parsed_y < -400) parsed_y = -400;

                // 先写完整待处理数据，最后递增序号作为原子发布点。
                // TIM2 即使在写入中途抢占，也只会看到上一个完整序号。
                pending_error_x = (int16_t)parsed_x;
                pending_error_y = (int16_t)parsed_y;
                pending_fire = (uint8_t)atoi(token3);
                rx_packet_sequence++;
            }
            
            rx_state = STATE_IDLE;
        } else {
            if (rx_index < RX_BUFFER_SIZE - 1) {
                rx_buffer[rx_index++] = byte;
            } else {
                rx_state = STATE_IDLE; // overflow
            }
        }
    }
    else if (rx_state == STATE_RECEIVING_TUNING)
    {
        if (byte == '}') {
            rx_buffer[rx_index] = '\0';
            
            // 解析 {Kp,Ki,Kd}
            char *token1 = strtok((char*)rx_buffer, ",");
            char *token2 = strtok(NULL, ",");
            char *token3 = strtok(NULL, ",");
            
            if (token1 && token2 && token3) {
                float new_kp = (float)atof(token1);
                float new_ki = (float)atof(token2);
                float new_kd = (float)atof(token3);

                // 只接受 GUI 支持范围内的有限参数，防止 NaN/Inf 绕过限速。
                if (isfinite(new_kp) && isfinite(new_ki) && isfinite(new_kd) &&
                    new_kp >= 0.0f && new_kp <= 2.0f &&
                    new_ki >= 0.0f && new_ki <= 1.0f &&
                    new_kd >= 0.0f && new_kd <= 1.0f) {
                    Kp = new_kp;
                    Ki = new_ki;
                    Kd = new_kd;
                }
            }
            
            rx_state = STATE_IDLE;
        } else {
            if (rx_index < RX_BUFFER_SIZE - 1) {
                rx_buffer[rx_index++] = byte;
            } else {
                rx_state = STATE_IDLE; // overflow
            }
        }
    }
    else if (rx_state == STATE_RECEIVING_COMMAND)
    {
        if (byte == '\n' || byte == '\r') {
            rx_buffer[rx_index] = '\0';
            if (strcmp((char*)rx_buffer, "STOP") == 0) {
                RequestStop();
            } else if (strcmp((char*)rx_buffer, "CENTER") == 0) {
                ResetPosition();
            } else if (strncmp((char*)rx_buffer, "LASER:", 6) == 0) {
                int state = atoi((char*)rx_buffer + 6);
                manual_laser_state = (state > 0) ? 1 : 0;
                Laser_SetState(manual_laser_state | current_fire);
                if (manual_laser_state) {
                    CDC_Transmit_FS((uint8_t*)"[OK] LASER_ON\r\n", 15);
                    HAL_GPIO_WritePin(LED_GPIO_Port, LED_Pin, GPIO_PIN_RESET);
                } else {
                    CDC_Transmit_FS((uint8_t*)"[OK] LASER_OFF\r\n", 16);
                    HAL_GPIO_WritePin(LED_GPIO_Port, LED_Pin, GPIO_PIN_SET);
                }
            } else if (strncmp((char*)rx_buffer, "POWER:", 6) == 0) {
                int pwr = atoi((char*)rx_buffer + 6);
                if (pwr < 0) pwr = 0;
                if (pwr > 100) pwr = 100;
                Laser_SetPower((uint8_t)pwr);
                char ack_buf[32];
                int len = snprintf(ack_buf, sizeof(ack_buf), "[OK] POWER:%d\r\n", pwr);
                CDC_Transmit_FS((uint8_t*)ack_buf, (uint16_t)len);
            }
            rx_state = STATE_IDLE;
            rx_index = 0;
        } else if (rx_index < RX_BUFFER_SIZE - 1) {
            rx_buffer[rx_index++] = byte;
        } else {
            rx_state = STATE_IDLE;
            rx_index = 0;
        }
    }
}
/* USER CODE END 0 */

/**
  * @brief  The application entry point.
  * @retval int
  */
int main(void)
{

  /* MCU Configuration--------------------------------------------------------*/

  /* Reset of all peripherals, Initializes the Flash interface and the Systick. */
  HAL_Init();

  /* Configure the system clock */
  SystemClock_Config();

  /* Initialize all configured peripherals */
  MX_GPIO_Init();
  MX_TIM2_Init();
  MX_TIM3_Init();
  MX_USB_DEVICE_Init();
  
  /* USER CODE BEGIN 2 */
  Laser_Init();
  // 启动 TIM2 10kHz 高频微步时钟中断
  HAL_TIM_Base_Start_IT(&htim2);
  /* USER CODE END 2 */

  /* Infinite loop */
  /* USER CODE BEGIN WHILE */
  uint32_t last_led_tick = 0;
  while (1)
  {
    /* USER CODE END WHILE */

    /* USER CODE BEGIN 3 */
    // 心跳指示灯 (每 500ms 翻转一次，直观确认 STM32 正常运行)
    if (HAL_GetTick() - last_led_tick >= 500) {
        last_led_tick = HAL_GetTick();
        HAL_GPIO_TogglePin(LED_GPIO_Port, LED_Pin);
    }

    // 板载按键检测 (PA2) - Active Low (按下接地)
    if (HAL_GPIO_ReadPin(KEY_GPIO_Port, KEY_Pin) == GPIO_PIN_RESET) 
    {
        HAL_Delay(20); // 防抖
        if (HAL_GPIO_ReadPin(KEY_GPIO_Port, KEY_Pin) == GPIO_PIN_RESET)
        {
             ResetPosition();
             while(HAL_GPIO_ReadPin(KEY_GPIO_Port, KEY_Pin) == GPIO_PIN_RESET);
        }
    }
  }
  /* USER CODE END 3 */

}

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
/* USER CODE BEGIN 4 */

/**
 * @brief 10kHz 硬件微步插补与 50Hz 增量 PID 核心中断回调
 */
void HAL_TIM_PeriodElapsedCallback(TIM_HandleTypeDef *htim)
{
  if (htim->Instance == TIM2)
  {
      // ==========================================================
      // [1] 脉冲清零 (Falling Edge: 保证 100μs 充沛的高电平脉宽)
      // ==========================================================
      if (pulse_active_x) {
          HAL_GPIO_WritePin(GPIOA, X_STP_Pin, GPIO_PIN_RESET);
          pulse_active_x = 0;
      }
      if (pulse_active_y) {
          HAL_GPIO_WritePin(GPIOA, Y_STP_Pin, GPIO_PIN_RESET);
          pulse_active_y = 0;
      }

      // 急停状态只由最高优先级 TIM2 修改，确保之后不再产生上升沿。
      if (stop_requested) {
          ApplyStopMotion();
          return;
      }

      // ==========================================================
      // [2] 连续相位 DDA 脉冲分配器 (Rising Edge)
      // 小数步跨 PID 周期保留，低速时不再发生 0/1 步量化跳变。
      // ==========================================================
      float abs_rate_x = fabsf(current_step_rate_x);
      if (abs_rate_x > 0.0f) {
          step_phase_x += abs_rate_x;
          if (step_phase_x >= STEP_TIMER_HZ) {
              step_phase_x -= STEP_TIMER_HZ;
              HAL_GPIO_WritePin(GPIOA, X_STP_Pin, GPIO_PIN_SET);
              pulse_active_x = 1;
          }
      }

      float abs_rate_y = fabsf(current_step_rate_y);
      if (abs_rate_y > 0.0f) {
          step_phase_y += abs_rate_y;
          if (step_phase_y >= STEP_TIMER_HZ) {
              step_phase_y -= STEP_TIMER_HZ;
              HAL_GPIO_WritePin(GPIOA, Y_STP_Pin, GPIO_PIN_SET);
              pulse_active_y = 1;
          }
      }

      // ==========================================================
      // [3] 50Hz 增量 PID 控制解算周期 (每 200 个 10kHz 滴答 = 20ms)
      // ==========================================================
      pid_subtick_counter++;
      if (pid_subtick_counter >= PID_SUBTICKS_PER_CYCLE)
      {
          pid_subtick_counter = 0;

          // STOP 后短暂丢弃串口中可能已经在途的旧运动包。
          if (stop_holdoff_cycles > 0U) {
              consumed_packet_sequence = rx_packet_sequence;
              stop_holdoff_cycles--;
              vision_timeout_counter = 0;
              return;
          }

          uint32_t latest_sequence = rx_packet_sequence;
          if (latest_sequence != consumed_packet_sequence) {
              // TIM2 优先级高于 USB；序号变化意味着待处理包已经完整写入。
              int16_t error_x = pending_error_x;
              int16_t error_y = pending_error_y;
              uint8_t fire = pending_fire;
              consumed_packet_sequence = latest_sequence;

              current_error_x = error_x;
              current_error_y = error_y;
              current_fire = fire;
              vision_timeout_counter = 0;

              // 视觉伺服自瞄开火联动 (PA7 使能 + PB0 PWM 占空比)
              Laser_SetState(current_fire | manual_laser_state);

              // --------------------------------------------------
              // 3.1 工业级视觉伺服闭环速度规划 (自适应动态阻尼 + 平滑过渡前馈)
              // --------------------------------------------------
              float raw_rate_x = 0.0f;
              if (abs(error_x) >= DEADZONE_PIXELS) {
                  float abs_err_x = fabsf((float)error_x);
                  float error_diff_x = (float)(error_x - prev_error_x);

                  // 自适应微分阻尼：远距离低阻尼(25.0f)全速狂飙，近距离重度阻尼(160.0f)强效急刹定点
                  float d_gain_x = (abs_err_x < 25.0f) ? 160.0f : 25.0f;
                  raw_rate_x = (Kp * (float)error_x * 55.0f) + (Kd * error_diff_x * d_gain_x);

                  // 动态静摩擦前馈：在准星中心 15px 内平滑衰减至 0，彻底消除慢速过冲往复摆动！
                  float breakaway_x = (abs_err_x < 15.0f) ? (FRICTION_BREAKAWAY_RATE_X * (abs_err_x / 15.0f)) : FRICTION_BREAKAWAY_RATE_X;
                  if (raw_rate_x > 0.0f) {
                      raw_rate_x += breakaway_x;
                  } else if (raw_rate_x < 0.0f) {
                      raw_rate_x -= breakaway_x;
                  }
              }
              prev_prev_error_x = prev_error_x;
              prev_error_x = error_x;

              float raw_rate_y = 0.0f;
              if (abs(error_y) >= DEADZONE_PIXELS) {
                  float error_diff_y = (float)(error_y - prev_error_y);
                  // Y 轴保持柔和舒适手感 (18.0f / 70.0f)
                  raw_rate_y = (Kp * (float)error_y * 18.0f) + (Kd * error_diff_y * 70.0f);
              }
              prev_prev_error_y = prev_error_y;
              prev_error_y = error_y;

              target_step_rate_x = LimitTrackingRate(raw_rate_x, error_x);
              target_step_rate_y = LimitTrackingRate(raw_rate_y, error_y);
          } else {
              // 40Hz 上位机与 50Hz 固件之间的空周期保持目标速度；
              // 最后一包到达后最多 500ms 执行电机平稳停止。
              vision_timeout_counter++;
              if (vision_timeout_counter >= VISION_TIMEOUT_CYCLES) {
                  current_error_x = 0;
                  current_error_y = 0;
                  target_step_rate_x = 0.0f;
                  target_step_rate_y = 0.0f;
                  current_step_rate_x = 0.0f;
                  current_step_rate_y = 0.0f;
                  current_fire = 0;
                  Laser_SetState(manual_laser_state);
              }
          }

          // ------------------------------------------------------
          // 3.4 电机执行层：加速度限制，并在换向前先减速到零
          // ------------------------------------------------------
          current_step_rate_x = RampMotorRate(current_step_rate_x, target_step_rate_x);
          current_step_rate_y = RampMotorRate(current_step_rate_y, target_step_rate_y);

          if (current_step_rate_x > 0.0f) {
              HAL_GPIO_WritePin(GPIOA, X_DIR_Pin, GPIO_PIN_SET);
          } else if (current_step_rate_x < 0.0f) {
              HAL_GPIO_WritePin(GPIOA, X_DIR_Pin, GPIO_PIN_RESET);
          } else {
              step_phase_x = 0.0f;
          }

          if (current_step_rate_y > 0.0f) {
              HAL_GPIO_WritePin(GPIOA, Y_DIR_Pin, GPIO_PIN_SET);
          } else if (current_step_rate_y < 0.0f) {
              HAL_GPIO_WritePin(GPIOA, Y_DIR_Pin, GPIO_PIN_RESET);
          } else {
              step_phase_y = 0.0f;
          }
      }
  }
}

/* USER CODE END 4 */
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


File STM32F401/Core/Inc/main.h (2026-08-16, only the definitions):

#define LED_Pin GPIO_PIN_13
#define LED_GPIO_Port GPIOC
#define X_STP_Pin GPIO_PIN_0
#define X_STP_GPIO_Port GPIOA
#define Y_STP_Pin GPIO_PIN_1
#define Y_STP_GPIO_Port GPIOA
#define KEY_Pin GPIO_PIN_2
#define KEY_GPIO_Port GPIOA
#define X_DIR_Pin GPIO_PIN_4
#define X_DIR_GPIO_Port GPIOA
#define Y_DIR_Pin GPIO_PIN_5
#define Y_DIR_GPIO_Port GPIOA
#define LASER_EN_Pin GPIO_PIN_7
#define LASER_EN_GPIO_Port GPIOA
#define LASER_PWM_Pin GPIO_PIN_0
#define LASER_PWM_GPIO_Port GPIOB

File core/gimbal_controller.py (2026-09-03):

# -*- coding: utf-8 -*-
"""
云台控制器核心模块 (Gimbal Controller Core)
================================================================================
本模块为 2 轴闭环激光云台的主控业务中枢，负责多模式运动学规划、定频闭环伺服、
光轴视差校准以及多重硬件安全联锁机制。

【核心职责 (Core Responsibilities)】
1. 定频高精度控制循环：默认 60Hz（可配置 10Hz~100Hz），与视觉传感器帧率深度同步。
2. 运动学与相对原点推算：航向角 (Yaw/Pan) 与俯仰角 (Pitch/Tilt) 的实时航位推算 (Dead Reckoning)。
3. 视觉引导闭环伺服：结合激光发射管光轴视差 (Boresight Calibration) 与 3 区非线性运动学平滑滤波。
4. 激光武器安全互锁：ARM / SAFE 状态机、友军防误伤切断、硬件看门狗与异常急停 (ESTOP)。
5. 多模式运动调度：自动视觉闭环追踪、FPS 鼠标精准瞄准、多档位键盘/按钮离散点动与平滑连续运动。

【架构设计规范 (Architectural Decoupling)】
- 严格分层解耦：Controller 层与 GUI 视图层完全解耦，不含任何图形界面渲染代码。
- 异步通信桥接：GUI 通过公共 API 调用控制器，控制器通过 Qt 信号向 GUI 异步派发遥测事件。
- 下位机通讯总线：通过 SerialThread 实例向下位机 (STM32F401) 异步下发高频实时数据帧。
- 集中式参数注入：所有控制增益、物理限制与机械参数均由 ControlConfig 与 VisionConfig 统一管理。
================================================================================
"""

import time
import math
import threading
from PyQt6.QtCore import QObject, pyqtSignal

from config import cfg
from config.control_config import ControlConfig
from core.control.error_processor import ErrorProcessor
from core.control.manual_aim_controller import ManualAimController
from utils.logger import Logger

logger = Logger("GimbalController")


class GimbalController(QObject):
    """
    云台控制器 (Gimbal Controller)

    封装所有云台闭环追踪计算、模式切换、鼠标瞄准及下位机指令下发业务。
    """

    # Qt 异步信号：通知 GUI 界面刷新运行状态与遥测数据
    status_update_signal = pyqtSignal(str)                  # 控制器状态/警报文本
    position_update_signal = pyqtSignal(float, float)       # X(Pan), Y(Tilt) 当前估算姿态角 (度)
    manual_target_update_signal = pyqtSignal(float, float)  # 鼠标瞄准相对中心的 Yaw/Pitch 目标角
    laser_state_signal = pyqtSignal(bool, bool, int)        # 激光状态 (armed: 保险, firing: 发射, power: 功率)
    speed_gear_changed_signal = pyqtSignal(int, float)      # 电机档位与倍率 (gear: 1/2/3, multiplier)

    def __init__(self, serial_thread):
        """
        初始化控制器

        Args:
            serial_thread: 串口通信线程实例
        """
        super().__init__()

        self.serial_thread = serial_thread

        # 3 级速度档位系统 (Gear 1: 精准微调 0.30x, Gear 2: 标准巡航 1.00x, Gear 3: 高速机动 2.20x)
        self.speed_gear: int = 2
        self.speed_multiplier: float = 1.0

        # 当前硬件软件相对原点与动态角度估算值 (单位: 角度 deg)
        self.servo_x: float = 0.0
        self.servo_y: float = 0.0

        # 挂载下位机 (STM32) 串口遥测数据接收槽函数
        if hasattr(self.serial_thread, "data_received_signal"):
            self.serial_thread.data_received_signal.connect(self._handle_serial_rx)

        # [激光子系统状态] 保险解锁 (armed)、开火中 (firing)、PWM 输出功率百分比 (0~100)
        self.laser_armed: bool = False
        self.laser_firing: bool = False
        self.laser_power: int = 100

        # [视觉误差前处理器] 负责归一化坐标转换与滤波（统一读取 ControlConfig 参数）
        self.error_processor = ErrorProcessor()

        # [最新目标误差样本] 记录视觉处理后的当前归一化像素偏差与时间戳
        self.current_error_x: int = 0
        self.current_error_y: int = 0
        self.last_vision_time: float = time.monotonic()

        # [运行模式开关]
        self.control_enabled: bool = False       # 自动视觉闭环追踪开关
        self.visual_input_enabled: bool = False  # 相机输入有效性标志

        # [FPS 鼠标手动瞄准控制器]
        self.manual_aim = ManualAimController(
            sensitivity=ControlConfig.MOUSE_SENSITIVITY,
            yaw_limits=(ControlConfig.MOUSE_YAW_MIN, ControlConfig.MOUSE_YAW_MAX),
            pitch_limits=(ControlConfig.MOUSE_PITCH_MIN, ControlConfig.MOUSE_PITCH_MAX),
        )
        self.manual_mouse_enabled: bool = False
        self.mouse_capture_active: bool = False
        self.manual_motion_active: bool = False
        self._motion_lock = threading.RLock()

        # [坐标轴反转设置] 从 ControlConfig 读取，适配正装/吊装等机械布局
        self.invert_x: bool = ControlConfig.INVERT_X
        self.invert_y: bool = ControlConfig.INVERT_Y

        # 串口通讯断开警报节流时间戳（避免短时间内重复刷屏）
        self.last_warn_time: float = 0.0

        # [手动平滑连续运动状态] 供 UI 按钮长按或键盘方向键连续操控
        self._manual_jog_active: bool = False
        self._manual_jog_axis: str = 'x'
        self._manual_jog_dir: int = 0

        # [控制主线程] 独立定频控制线程（支持 60Hz 实时同步），彻底解耦 Qt GUI 主线程
        self.is_running = True
        self.control_thread = threading.Thread(target=self._run_control_loop, daemon=True)
        self.control_thread.start()

    def set_speed_gear(self, gear: int) -> None:
        """
        设置电机速度档位

        档位说明:
            - Gear 1 (0.30x): 远程高精度瞄准、防抖微调
            - Gear 2 (1.00x): 标准巡航速度与常规视觉追踪
            - Gear 3 (2.20x): 快速大角度大行程转动机动

        Args:
            gear: 档位序号 (1, 2, 3)
        """
        gear = max(1, min(3, int(gear)))
        self.speed_gear = gear
        if gear == 1:
            self.speed_multiplier = 0.30
            gear_name = "GEAR 1 (SLOW / PRECISION 0.3x)"
        elif gear == 2:
            self.speed_multiplier = 1.00
            gear_name = "GEAR 2 (NORMAL 1.0x)"
        else:
            self.speed_multiplier = 2.20
            gear_name = "GEAR 3 (FAST / TURBO 2.2x)"

        self.speed_gear_changed_signal.emit(self.speed_gear, self.speed_multiplier)
        self.status_update_signal.emit(f"⚡ 电机速度已切换为: {gear_name}")
        logger.info(f"[CONTROLLER] 电机速度档位更新: {gear_name}")

    def _handle_serial_rx(self, line: str) -> None:
        """
        解析下位机 (STM32) 上报的姿态角度或系统状态报文

        支持的报文样例:
            - "P: 12.3, -4.5"
            - "POS: <12.3, -4.5>"

        Args:
            line: 串口接收缓冲区提取出的单行文本
        """
        try:
            clean = line.strip()
            if ("P:" in clean or "POS:" in clean) and "," in clean:
                parts = clean.replace("POS:", "").replace("P:", "").replace("<", "").replace(">", "").split(",")
                if len(parts) >= 2:
                    px = float(parts[0].strip())
                    py = float(parts[1].strip())
                    self.servo_x = px
                    self.servo_y = py
                    self.position_update_signal.emit(self.servo_x, self.servo_y)
        except Exception:
            pass

    def set_laser_armed(self, armed: bool) -> None:
        """
        设置激光安全保险状态 (ARM / SAFE)

        安全策略:
            当锁定保险 (armed=False) 时，若当前激光正在发射，将立即强制切断并下发停火指令。

        Args:
            armed: True 为解除保险允许发射，False 为上锁保险严禁发射
        """
        self.laser_armed = armed
        if not armed and self.laser_firing:
            self.laser_firing = False
            if self._is_serial_connected():
                self.serial_thread.send_command("!LASER:0\n")
        self.laser_state_signal.emit(self.laser_armed, self.laser_firing, self.laser_power)
        logger.info(f"[LASER] 激光保险状态: {'🔴 ARMED' if armed else '🟢 SAFE'}")

    def set_laser_firing(self, firing: bool) -> None:
        """
        触发或停止激光物理发射

        安全检查:
            若激光处于 SAFE 保险上锁状态，将拒绝触发发射并输出告警。
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

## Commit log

2026-02-08 Fix: Add missing Sync and Start Control buttons to GUI layout
2026-02-09 Add circuit schematic diagram to README
2026-02-09 Add 1000µF capacitor to hardware list
2026-02-10 重构：模块化架构改造与功能增强
    主要改进：
    1. 配置系统重构
    - 新增config/目录，将配置模块化为PID、视觉、硬件三个独立配置类
    - 保持向下兼容性，支持旧代码
    - 优化PID默认参数（Kp=0.4, Kd=0.2），更温和稳定
    2. GUI组件化重构
    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
2026-02-12 优化：PID参数调整与用户体验改进
    - PID参数优化适配新摄像头
    - 新增摄像头选择面板，支持动态切换
    - PID调参面板可折叠，节省界面空间
    - GUI支持滚动，适配小屏幕
    - 新增蓝色物体居中追踪模式
    - 视觉HSV优化，提升暗光环境识别
    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
2026-03-12 chore: 重构前存档 (pre-refactor snapshot)
2026-03-12 refactor: Phase 1-3 完成 - 配置整理 + 控制层重构
    Phase 1: 删除根目录冗余 config.py（已被 config/ 目录覆盖）
    Phase 2: 新增 config/control_config.py，集中管理PID/速度/死区/缩放参数
    简化 config/__init__.py，移除冗余属性映射
    Phase 3: 新增 core/control/error_processor.py（误差缩放+滤波）
    重构 core/gimbal_controller.py，消除所有硬编码魔法数字
    所有控制参数统一从 ControlConfig 读取
    [gimbal_controller.py]
2026-03-12 refactor: Phase 4 完成 - 视觉层重构
    新增 vision/detector.py（纯视觉检测器，无控制逻辑）
    重写 vision/worker.py：
    - 移除硬编码死区(deadzone=30)和误差缩放(scale_factor)
    - BLUE_TRACKING 模式: 发送原始坐标 target_pos_signal
    - TRACKING 模式: 保留两点误差 control_signal
    更新 gui/main_window.py：
    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
2026-03-12 refactor: Phase 5 完成 - 启用日志系统
    将以下模块的所有 print() 替换为 Logger 调用：
    - core/gimbal_controller.py → Logger("GimbalController")
    - vision/worker.py → Logger("VisionWorker")
    - core/serial_thread.py → Logger("SerialThread")
    - config/__init__.py → Logger("Config")
    日志级别规范：
    - logger.info() : 正常状态变化（连接、模式切换等）
    - logger.warning() : 串口未连接、视觉信号丢失、限位触发
    - logger.error() : 异常捕获
    - logger.debug() : 手动移动计算、发送命令
    [gimbal_controller.py, serial_thread.py]
2026-03-12 refactor: Phase 6 完成 - 删除冗余文件，清理旧引用
    删除 config/pid_config.py（参数已全部迁移至 ControlConfig）
    更新 gui/widgets/pid_tuner.py：
    - _on_reset_clicked 改用 ControlConfig 代替 PIDConfig
    - 格式修正：Ki 显示精度 .3f
    现所有 PID 配置统一由 config/control_config.py 管理
    [pid_tuner.py]
2026-03-12 fix: 修复测试阶段发现的问题(串口列表/阈值/排版)
    1. config/vision_config.py: 提高HSV蓝色的V/S下限(30->60, 100->140)，避免将黑色(暗色)物体误判为蓝色
    2. gui/widgets/serial_panel.py: 引入 serial.tools.list_ports 自动检测可用COM口，替换原硬编码的COM1-COM10
    3. gui/main_window.py: 为status_label启用setWordWrap(True)，防止长错误文本(串口连接失败)撑宽导致UI变形
    [serial_panel.py]
2026-03-12 fix: 修复 main.py 中 logger 导入导致的 SyntaxError
    此前的批量替换脚本意外将 logger 的 import 语句插在 main.py 的 try-except 块内部，导致语法错误。
    现在将其移至顶部的全局导入区域，并修复了缩进。
2026-03-12 fix: 修复PID设定与死区生效问题
    1. 修复 PIDTuner GUI 的“重置按钮”错误读取了已经被滑块覆写的全局变量，现已改为读取硬编码的出厂默认值兜底。
    2. 修复 ControlConfig 中死区(deadzone)设定过大的问题（之前高达30像素），导致微小的PID变化完全无法通过死区检测使得调参感觉“无反应”。调整后近点死区为12px，使控制更加锐利和可见。
    [pid_tuner.py]
2026-03-12 fix: 修复关闭窗口时 Python 无响应的错误
    问题原因：
    Qt在关闭事件 `closeEvent` 中使用了 `thread.wait()` 进行了死等。而在 Windows 系统下，OpenCV 调用 DSHOW 后端（`cv2.CAP_DSHOW`）释放摄像头时极容易被阻塞挂起，这就导致了图形界面一直无法获得响应而被强制认定为“程序已死”。
    修复方法：
    在 `closeEvent` 里的所有的 `.wait()` 都加入了 `(1000)` 毫秒强制超时限制，只要1秒钟等不到就主动放行销毁主界面进程，交由操作系统内核接手回收那些阻塞住的资源了。
2026-03-12 fix: 修复由于帧延迟和死区引发的画圈摆动(Oscillation)以及UI未同步bug
    1. 修复 PID_Tuner 滑块UI：在点击“重置兜底值”后，增加了 `self.pid_changed.emit()`，确保主窗口和底层 Controller 真正收到修改，而不只是表面重绘 UI。
    2. 修复视觉核心底层漏洞：删减了 vision/worker.py 里用于限制CPU占用的 `time.sleep(0.01)`。摄像头自带硬件帧阻塞率（通常15~60FPS），额外加 sleep 会导致读取帧的速度慢于硬件产生帧的速度，长期挤压产生严重的“相移缓存延迟(Phase lag)”，此举解决了画面感觉慢、不跟手的底层顽疾。
    3. 缓解追随摆动(Oscillation)：增加基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
    [pid_tuner.py]
2026-03-12 fix: 修复更改摄像框分辨率后追踪准星中心错位的问题
    原因：先前代码将摄像头的物理宽度和相对画面的宽度作为固定魔法常数(320x240)写死。修改配置面板分辨率后，底层处理算法的锚点并没有跟随物理分辨率动态翻倍，这就导致越高清模式准星偏得越离谱。
    修复操作：
    在 `vision/worker.py` 获取到摄像头实际反馈的新 `(w, h)` 分辨率后，实时通过覆盖全局单例属性动态赋予 `VisionConfig.CENTER_X / Y`，使 GimbalController 取到的靶心位置始终在物理正中心。
    同时写入检测代码警告低光照下的主动降帧限流机制。
2026-03-12 fix: 修复更改分辨率后摄像头选择下拉框文本不同步的问题
2026-03-12 chore: 全面清除控制台打印(print)残留，替换为标准 logger 模块
    1. 清除了在 `gui/main_window.py`、`gui/test_panel.py` 和 `config/__init__.py` 中因为我中断了自动化脚本而残留下的零散 `print` 语句。
    2. 将它们全部分类规范化为了 `logger.info()` 等格式，使项目现在彻底摆脱了未经管理的随意打印。
2026-03-12 chore: 更新 README 配置说明，并将 vision/worker.py 重命名为 vision_worker.py 以提高辨识度
2026-03-12 feat: 添加开启和关闭摄像头的独立按钮功能，防止开局自动强制启动画面
2026-03-12 fix: 修复 camera_panel 缺少 QHBoxLayout 引用导致的打不开问题
    [camera_panel.py]
2026-03-12 perf: 提升下位机和上位机波特率至 115200，以降低通信延迟感
2026-03-12 v0.2.0: Hardware sync, 720p 60fps unlocked, and UI/PID tuning refactor.
2026-03-12 ### [v0.2.0] - 2026-03-12 - **Power System Upgrade**: Integrated a 12V DC Adapter with an XL4016 Buck Converter to provide a dedicated, stable 6V power supply for the gimbal servos. - **Framework Ref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
2026-03-19 feat(yolo26): upgrade to YOLO26 core, multithread PID & harden STM32 safety logic - v0.3.6
2026-08-09 feat: 新增鼠标瞄准控制功能 (manual mouse control & aiming)
2026-08-16 feat: v0.4.0 - MKS SERVO42C closed-loop stepper upgrade, 10kHz DDA pulse generator, industrial safety system & keyboard control
2026-08-16 feat: v0.4.1 - Arducam AR0234 Global Shutter camera adaptation, YOLO26 CUDA acceleration & async visual pipeline
2026-08-16 feat: v0.4.4 - Industrial Visual Servo closed-loop, adaptive differential damping & 9000 step rate tracking
2026-08-16 feat(webui): Add futuristic HUD, 3D yellow gimbal (40x10x8cm), blue color tracking, camera selector, and laser shockwave pulse
2026-08-16 fix(sync): Ensure 100% synchronized continuous laser audio, 3D beam, expanding shockwaves, and hold-to-fire button
2026-08-16 release: v0.4.5 - Savunma YOLO26 adaptation, dynamic lead compensation, anti-jello and overshoot elimination
    [gimbal_controller.py, mode_panel.py]
2026-08-16 feat(camera): Add dynamic camera device scanning, resolution/FPS info, and rescan controls
2026-08-16 fix(webui): Asynchronous non-blocking camera init and robust SPA catch-all routing
2026-08-16 feat(webui): Add dynamic COM port selector with STM32 auto-detection and 1920x1200 60FPS MJPG camera support
2026-08-16 feat(laser): Add PB0 PWM laser weapon system, STM32 1kHz TIM3 driver, and 100% English GUI overhaul
2026-08-18 docs: modernize Phase 3/4 industrial roadmap and purge legacy MG996R servo configs
2026-08-18 fix(gui): Fix IFF friendly protection logic, HUD reticle targeting and live detection table
    [detection_panel.py]
2026-08-18 fix(vision): Fix missing math import in YOLO tracking loop and optimize FPS pipeline
    [gimbal_controller.py]
2026-08-18 fix(yolo): Add temporal anti-jitter filter for F-16 and enhance thin missile detection
2026-08-18 fix(yolo): Enforce strict confidence threshold filtering on both tracker and UI pipeline
2026-08-18 fix(gui): Stabilize DetectionPanel layout, eliminate height flicker, and optimize 60FPS UI repaints
    [detection_panel.py]
2026-08-18 feat(mission): Implement Stage 3 autonomous IFF competition sequence with live countdown, e-stop and safe shutdown
2026-08-18 fix(mission): Fix ModePanel button group reference and ensure crash-free execution
    [stage3_mission_director.py, stage3_mission_panel.py]
2026-08-18 feat(control): Add dedicated manual motor jog D-Pad to ControlPanel and boost jog speeds for crisp response
2026-08-18 fix(gui): Fix missing QGridLayout import in control_panel.py
    [control_panel.py]
2026-08-18 feat(gui): Add top-left reticle zoom scope (PiP), zoom slider & keyboard shortcuts, video recording button, and revert ControlPanel jog
    [camera_view.py, control_panel.py]
2026-08-18 fix(vision): Align PiP zoom scope precisely with crosshair, remove synthetic PiP reticle, and support full calibration saving
    [camera_view.py]
2026-08-18 feat: Synchronize PiP scope crop with big crosshair in real time, add 3-button video recording (Record, Pause/Resume, Stop)
2026-08-18 feat: Add English HUD telemetry OSD to video recordings, add PiP center reticle, and persist camera & STM32 connection settings to device_settings.json
2026-08-18 feat: Add 3-speed motor gear system with 1/2/3 shortcuts, dynamic real-time angle telemetry tracking, and live STM32 serial monitor
    [camera_view.py, gimbal_controller.py, serial_panel.py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]
2026-08-18 fix: Fix camera startup auto-activation and render telemetry HUD on live screen at all times
    [camera_panel.py, camera_view.py]
2026-08-18 fix: Fix live camera rendering pipeline to guarantee screen displays live feed seamlessly
    [camera_view.py]
2026-08-18 fix: Fix recording multithreading race crash and eliminate hardware probe device busy conflict on Camera 1
    [camera_panel.py]
2026-08-18 fix: Fix motor motion crash by batching serial monitor logs, make manual motor & keyboard control panel always visible on main interface
    [serial_panel.py]
2026-08-18 fix: Strengthen Y-axis tracking authority to pull crosshair into target center and optimize IFF for blue targets under ambient yellow light
    [gimbal_controller.py]
2026-08-18 fix: Ensure continuous minimum torque command on small residual error to prevent friction stall and achieve 100% bullseye lock-in
    [gimbal_controller.py]
2026-08-18 feat: Add Orange Balloon Pop Mode (BALLOON_HUNT) with auto-tracking, 100% laser touch firing, and continuous loop until balloon explodes without altering existing modes
2026-08-18 feat: Add strict geometric ellipse/roundness filtering to balloon pop mode to reject non-balloon objects like tables, wires, skin and clutter
2026-08-18 feat: Add multi-balloon persistent lock-on and sequential kill chain to eliminate Balloon 1 first, then auto-switch to Balloon 2 upon destruction
2026-08-18 fix: Update Stage 3 Mission fire control to slew and lock on target first before firing, and maintain continuous tracking laser fire until target destruction
    [stage3_mission_director.py]
2026-08-18 fix: Eliminate fast-forward recording speed and frame rate drops during laser firing by implementing wall-clock constant frame rate (CFR 30fps) synchronization
2026-08-20 feat(stage3): add Stage 3 Balloon Defense mode, zero-flicker spatial multi-target tracker, embedded workflow panel, and IFF separation
    [BALISTIK_FUZE.stl, F16.stl, HELIKOPTER.stl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]
2026-09-03 docs: modernize code documentation and remove legacy servo remnants

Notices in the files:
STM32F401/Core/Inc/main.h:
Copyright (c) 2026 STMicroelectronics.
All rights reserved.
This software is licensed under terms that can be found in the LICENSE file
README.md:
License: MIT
